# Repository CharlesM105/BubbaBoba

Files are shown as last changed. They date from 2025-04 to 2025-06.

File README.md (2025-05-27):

</head>
<body>

<h1>🧋 Bubba Boba</h1>
<p><strong>An Arduino-powered, fully-automated boba drink dispenser.</strong></p>

<div class="section">
  <h2>✨ Project Overview</h2>
  <p><strong>Bubba Boba</strong> is a fully autonomous boba drink-making robot built using two coordinated Arduino boards: an Arduino Mega and an Arduino Uno. The Mega handles all user interface logic, relay sequencing, and drink recipe control. The Uno exclusively controls mechanical movement: stepper motors, servos, limit switches, and mixers. Together, they synchronize to deliver a customizable, fully-automated boba experience.</p>
  <p>Users can navigate a menu via rotary encoder and LCD display, select a drink, and watch as the machine pours milk, adds flavor, mixes the drink, and finally dispenses boba. A final presentation sequence slides the cup out to the user for pickup. A full-system cleaning mode is also included for maintenance.</p>
</div>

<div class="section">
  <h2>🧠 How It Works (System Architecture)</h2>
  <ul>
    <li><strong>Arduino Mega:</strong> Handles all logic, UI, and relay control.
      <ul>
        <li>Displays menu on LCD and processes rotary encoder input</li>
        <li>Controls timing and sequencing of drink-making steps</li>
        <li>Manages relays for milk and flavor dispensing</li>
        <li>Sends light signal to Uno via onboard LED or relay circuit</li>
      </ul>
    </li>
    <li><strong>Arduino Uno:</strong> Handles mechanical automation.
      <ul>
        <li>Homes all axes on startup using limit switches (X, Y, Z)</li>
        <li>Moves cup into mixing, dispensing, and boba positions</li>
        <li>Operates syrup servo, mixer motor, and boba shaker</li>
        <li>Begins execution when a photoresistor detects the light signal from Mega</li>
      </ul>
    </li>
    <li><strong>Communication:</strong>
      <ul>
        <li>Photoresistor on Uno reads light intensity from a pin-controlled LED on Mega</li>
        <li>Simple analog-based “GO” signal used to trigger the movement sequence</li>
        <li>One-way communication — minimal wiring, no serial protocol needed</li>
      </ul>
    </li>
    <li><strong>Scripts:</strong>
      <ul>
        <li><code>main.ino</code> – runs on Mega (UI, logic, pumps, LED)</li>
        <li><code>movement_sequence.ino</code> – runs on Uno (motors, servo, mixer)</li>
        <li>All other .ino files are test scripts for subsystems (not used in production)</li>
      </ul>
    </li>
  </ul>
</div>

<div class="section">
  <h2>🧰 Features</h2>
  <ul>
    <li>Rotary encoder + 20x4 LCD menu system</li>
    <li>Preset drinks: Classic Tea, Strawberry Milk, Taro Milk Tea</li>
    <li>Servo-controlled syrup dispenser</li>
    <li>Milk and flavor pumps controlled by relays</li>
    <li>Stepper gantry motion on 3 axes</li>
    <li>Boba dispensing via dedicated stepper + shaker motor</li>
    <li>NeoPixel LED animations during each drink phase</li>
    <li>Full-system cleaning mode (30s all-pump activation)</li>
    <li>Diagnostics + manual axis control menus</li>
  </ul>
</div>

<div class="section">
  <h2>💸 Updated Cost Breakdown</h2>
  <p><strong>All items (except milk) were purchased from Amazon.</strong></p>
  <p><strong>The lead screw kit used is generic and is applied throughout the project.</strong></p>
  <p><strong>More detailed parts, source links, and specifications are included in the separate BOM file (Bill of Materials).</strong></p>

  <table>
    <thead>
      <tr><th>Item</th><th>Quantity</th><th>Unit Price</th><th>Total Price</th></tr>
    </thead>
    <tbody>
      <tr><td><strong>Electronics & Hardware</strong></td><td></td><td></td><td></td></tr>
      <tr><td>Arduino Mega 2560</td><td>1</td><td>$49.65</td><td>$49.65</td></tr>
      <tr><td>I2C 20x4 LCD Display</td><td>1</td><td>$13.76</td><td>$13.76</td></tr>
      <tr><td>Rotary Encoder</td><td>1</td><td>$8.89</td><td>$8.89</td></tr>
      <tr><td>V-Slot Screws (25 pcs)</td><td>1</td><td>$2.36</td><td>$2.36</td></tr>
      <tr><td>Buttons (for axis limits)</td><td>3</td><td>$1.00</td><td>$3.00</td></tr>
      <tr><td>Lead Screw Kit</td><td>1</td><td>$18.45</td><td>$18.45</td></tr>
      <tr><td>Stepper Motor (Single)</td><td>1</td><td>$14.32</td><td>$14.32</td></tr>
      <tr><td>Motor Drivers (4-pack)</td><td>1</td><td>$9.99</td><td>$9.99</td></tr>
      <tr><td>12V DC Motor</td><td>1</td><td>$14.99</td><td>$14.99</td></tr>
      <tr><td>Mini 5V Motors (3-pack)</td><td>1</td><td>$7.99</td><td>$7.99</td></tr>
      <tr><td>Buck Converters (3-pack)</td><td>1</td><td>$14.99</td><td>$14.99</td></tr>
      <tr><td>120mm Fans</td><td>2</td><td>$6.00</td><td>$12.00</td></tr>
      <tr><td>Acrylic Sheets</td><td>2</td><td>$10.00</td><td>$20.00</td></tr>
      <tr><td>Cups (100-pack)</td><td>1</td><td>$16.99</td><td>$16.99</td></tr>
      <tr><td>Boba Flavor Kits</td><td>3</td><td>$22.00</td><td>$66.00</td></tr>
      <tr><td>Milk</td><td>2</td><td>$4.50</td><td>$9.00</td></tr>
      <tr><td>Thin Wood Sheets (6-pack)</td><td>1</td><td>$10.00</td><td>$10.00</td></tr>
      <tr><td>Diaphragm Pumps</td><td>4</td><td>$8.00</td><td>$32.00</td></tr>
      <tr><td>LED Strips (optional)</td><td>2</td><td>$10.00</td><td>$20.00</td></tr>
      <tr><td>Relay Modules (10-pack)</td><td>1</td><td>$12.00</td><td>$12.00</td></tr>
      <tr><td>Tubing</td><td>1</td><td>$5.00</td><td>$5.00</td></tr>
      <tr><td><strong>Recycled Ender 3 V1 Parts (Rails, Mounts, Power Supply)</strong></td><td>–</td><td>$0.00</td><td>$0.00</td></tr>
      <tr><td>Black PLA (2 partial rolls)</td><td>1</td><td>$15.00</td><td>$15.00</td></tr>
      <tr><td>Gold PLA (partial roll)</td><td>1</td><td>$7.50</td><td>$7.50</td></tr>
      <tr><td>Gray PLA (partial roll)</td><td>1</td><td>$7.50</td><td>$7.50</td></tr>
      <tr><td>Clear PLA (partial roll)</td><td>1</td><td>$7.50</td><td>$7.50</td></tr>
      <tr><td>White PLA (partial roll)</td><td>1</td><td>$7.50</td><td>$7.50</td></tr>
      <tr><th colspan="3">Total Estimated Cost</th><th>$450.83</th></tr>
    </tbody>
  </table>

  <h3>📝 Notes</h3>
  <ul>
    <li>Prices are based on average market values as of May 2025 and may vary depending on supplier and shipping.</li>
    <li><strong>Tariff and import duty costs are not reflected in these estimates.</strong></li>
    <li>Partial PLA rolls are estimated at 50% of a full roll (approx. 500g).</li>
    <li>Optional components (e.g., LED strips) can be excluded to lower costs.</li>
    <li>Most <strong>design elements</strong> were 3D printed; their cost is factored into filament pricing.</li>
  </ul>
</div>

<div class="section">
  <h2>📊 Project Timeline (Gantt Chart)</h2>
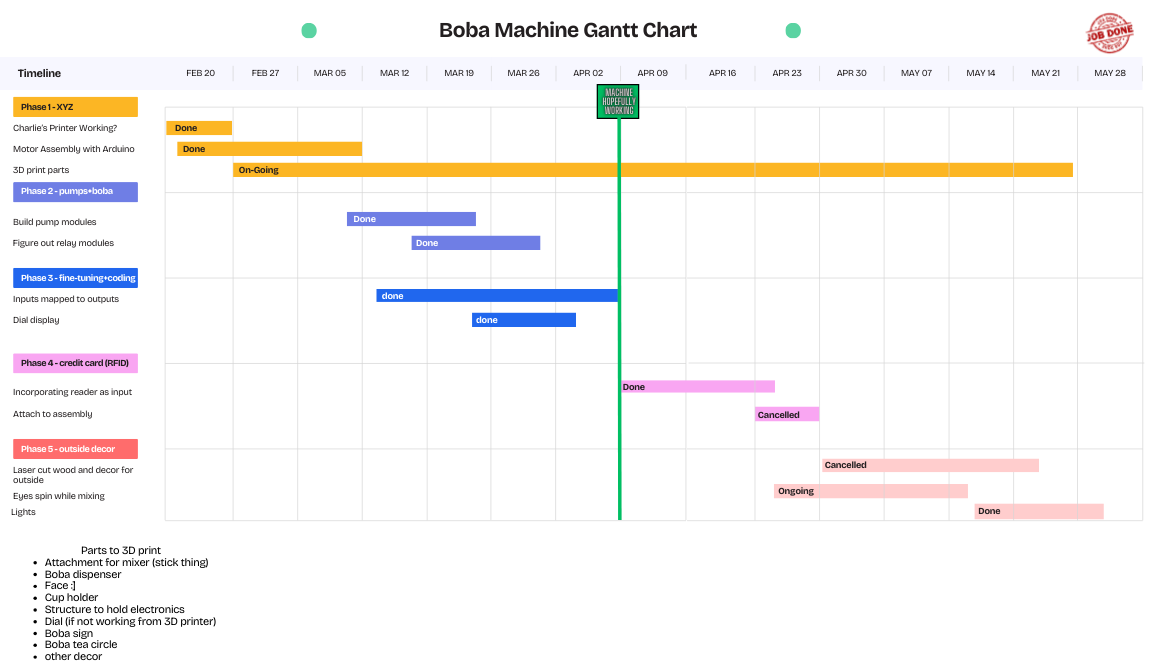
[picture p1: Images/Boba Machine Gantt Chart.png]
Bubba Boba Gantt Chart
  
</div>

<div class="section">
  <h2>📸 Demo Gallery</h2>
  <div>
    <h4>Final Build</h4>
    Final Build
    <h4>LCD UI</h4>
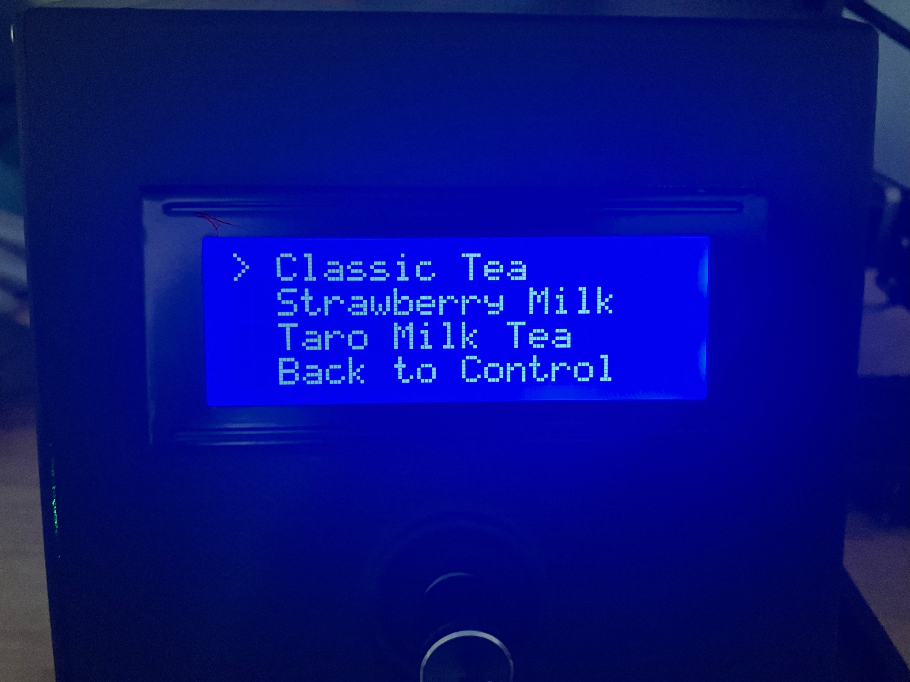
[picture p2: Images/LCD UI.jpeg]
LCD UI
    
    <h4>Ground Zero (Workstation Chaos)</h4>
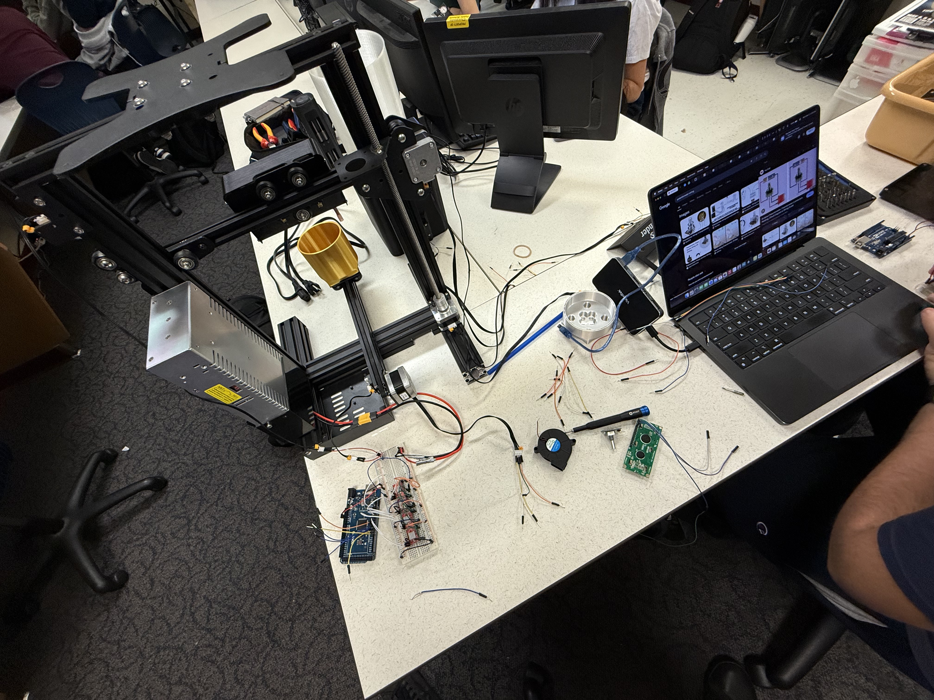
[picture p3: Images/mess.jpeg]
Ground Zero
    
    <h4>LED Strip Animation</h4>
    LED Strip Animation
    <h4>Stepper Motor Homing Sequence</h4>
    Stepper Motor Gantry
    <h4>Main Board Wiring</h4>
    Main Board
    <h4>Stepper Motors on Mega</h4>
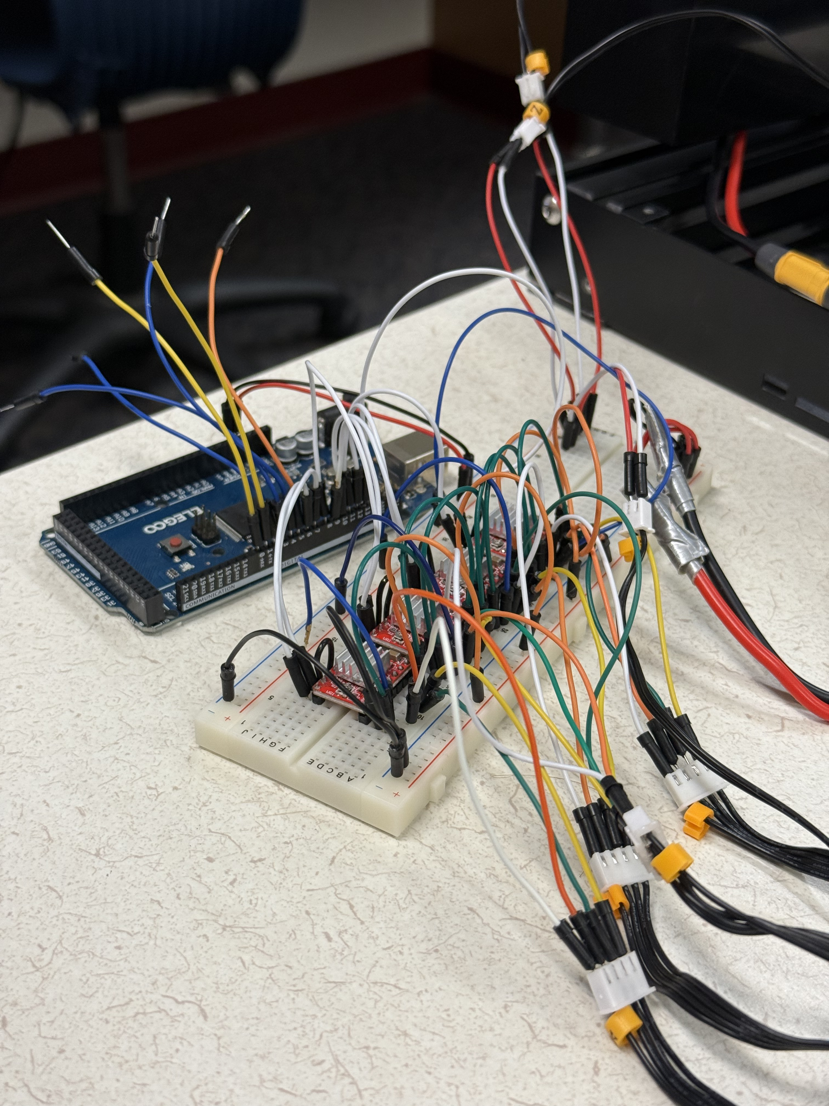
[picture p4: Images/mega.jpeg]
Stepper Motors
    
    <h4>Wire Management</h4>
    Wires
  </div>
</div>

<div class="section">
  <h2>🔌 Wiring Overview</h2>
  <p>All wiring documentation is included in <code>/docs</code>. Major components include:</p>
  <ul>
    <li>10V power for motors and pumps</li>
    <li>6V regulated for logic boards</li>
    <li>Limit switches on all axes</li>
    <li>Relay-controlled liquid pumps</li>
    <li>LED → photoresistor communication line between Mega and Uno</li>
  </ul>
</div>
</div>
      <h2>🔌 Wiring Diagram</h2>
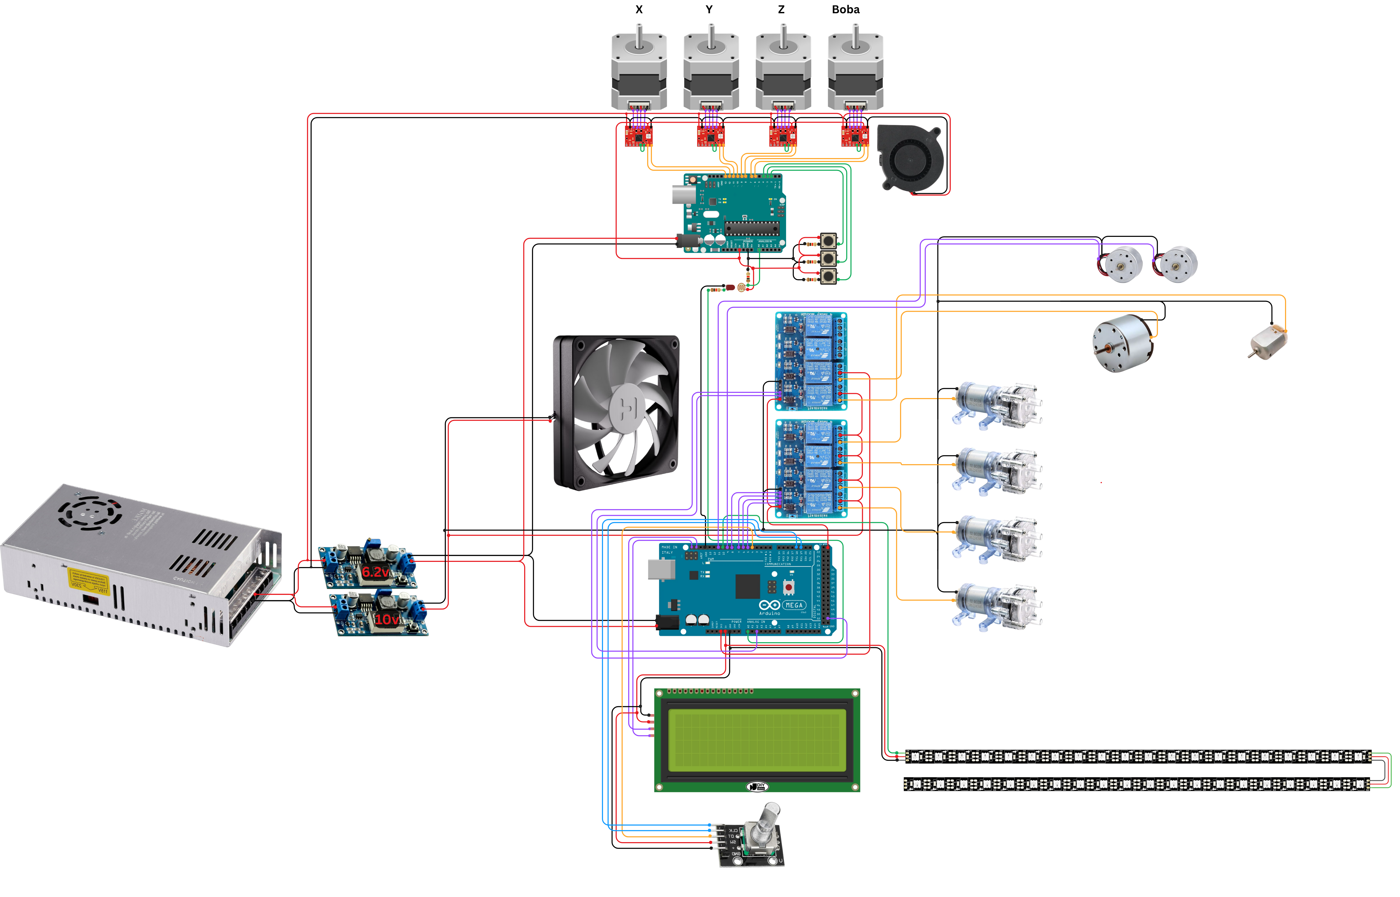
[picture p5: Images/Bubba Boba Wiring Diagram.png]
Bubba Boba Gantt Chart
  

<div class="section">
  <h2>📜 License</h2>
  <p>This project is licensed under the <a href="https://opensource.org/licenses/MIT" target="_blank">MIT License</a>.</p>
</div>

<div class="section">
  <h2>🙌 Credits</h2>
  <p>Created by <strong>Charles Mastromatteo, Sabrina Maule, and Vincent Larson</strong></p>
  <p>Special thanks to: Arduino forums, Adafruit libraries, and the online maker community.</p>
</div>

</body>
</html>

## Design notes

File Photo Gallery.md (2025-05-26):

<!DOCTYPE html>
<html lang="en">
<head>
  <meta charset="UTF-8">

</head>
<body>

  <h1>📸 Bubba Boba Photo Gallery</h1>

  <div class="gallery">
    <div class="photo-box">
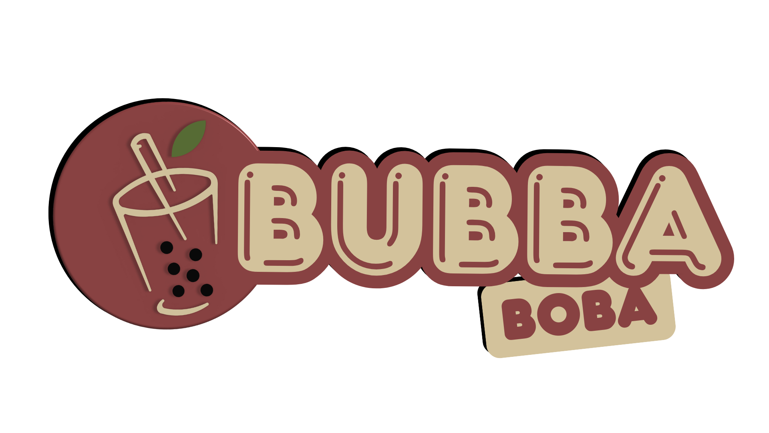
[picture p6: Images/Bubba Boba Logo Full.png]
Insert Image 1
      
    </div>
    <div class="photo-box">
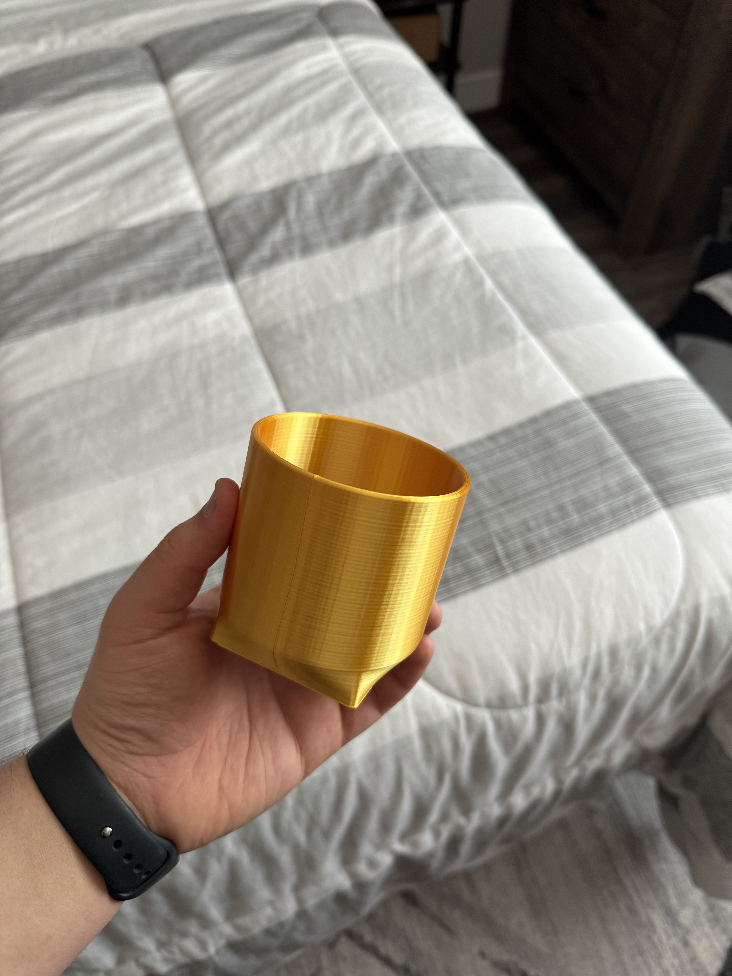
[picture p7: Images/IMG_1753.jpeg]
Insert Image 2
      
    </div>
    <div class="photo-box">
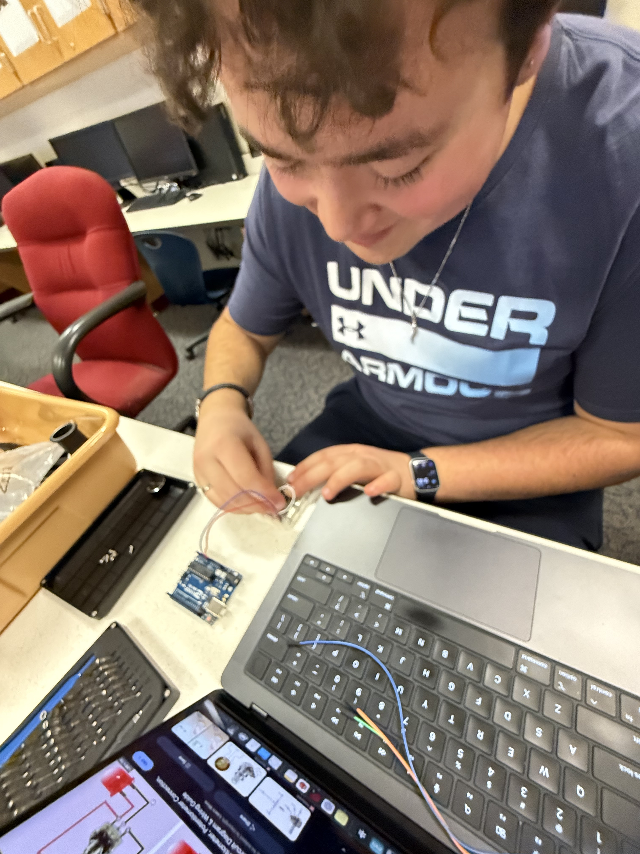
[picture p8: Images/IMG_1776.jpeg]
Insert Image 3
      
    </div>
    <div class="photo-box">
      Insert Image 4
    </div>
    <div class="photo-box">
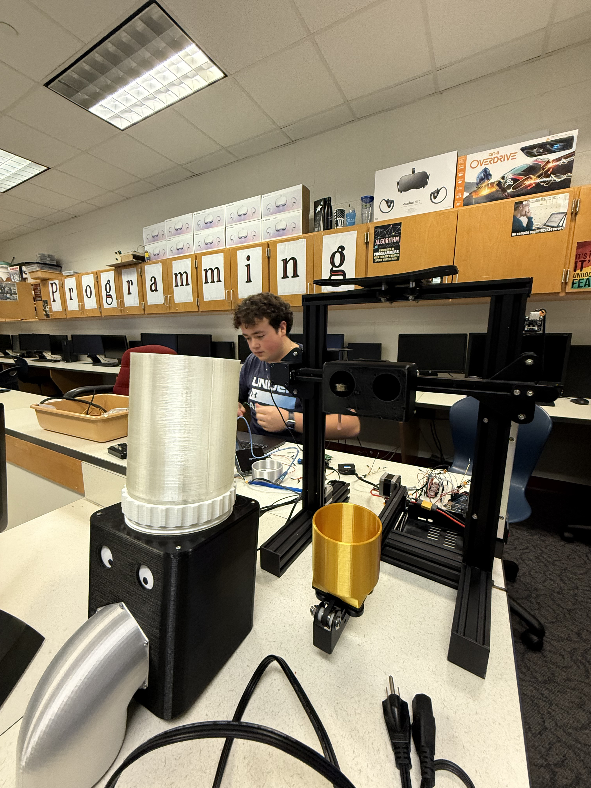
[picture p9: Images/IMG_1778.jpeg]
Insert Image 5
      
    </div>
    <div class="photo-box">
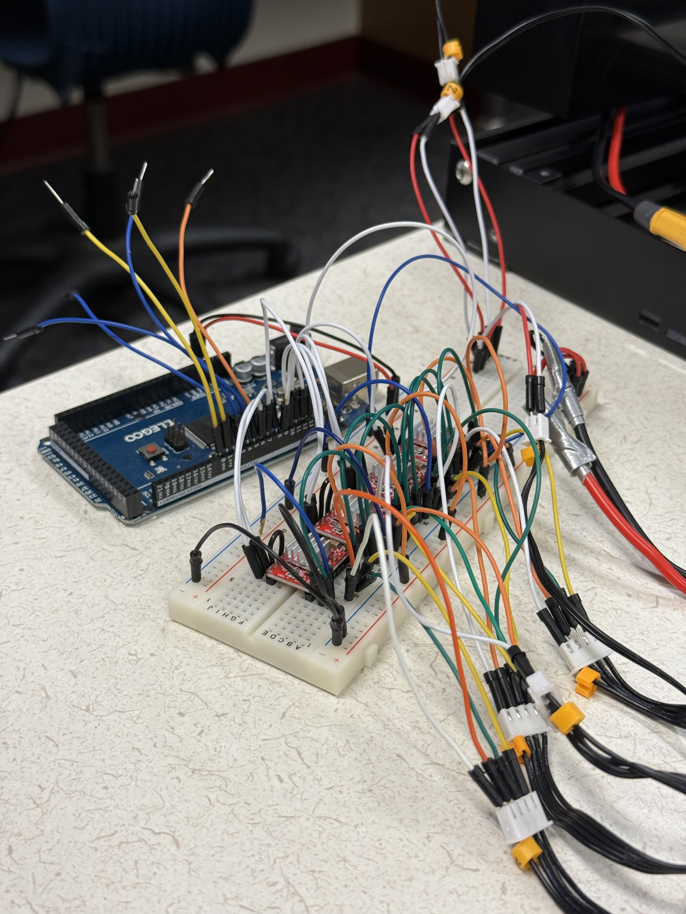
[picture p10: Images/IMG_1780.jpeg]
Insert Image 6
      
    </div>
        <div class="photo-box">
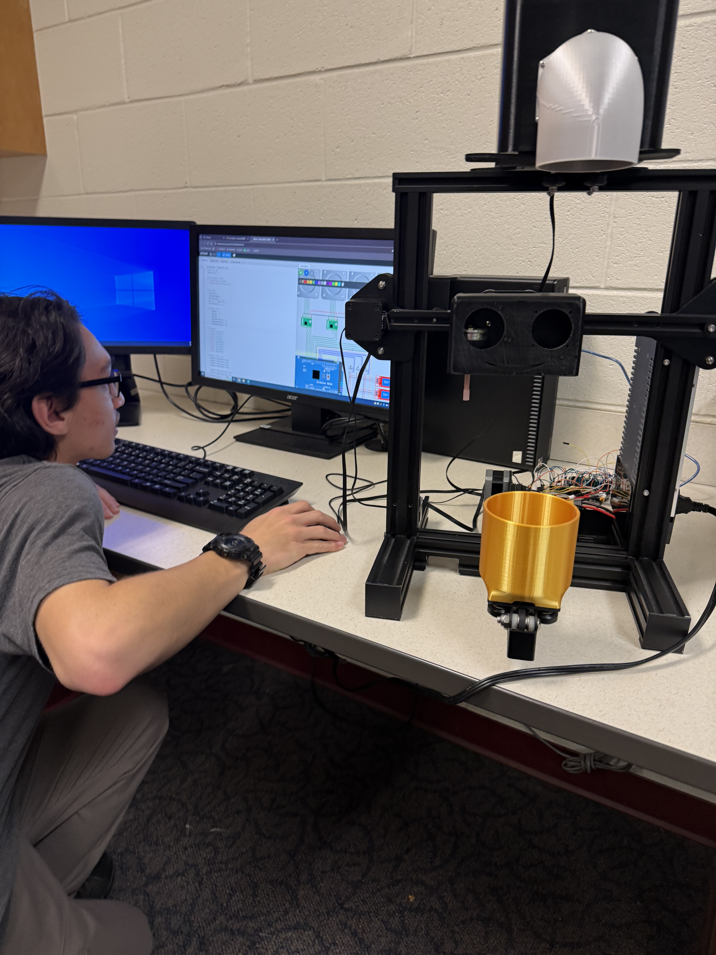
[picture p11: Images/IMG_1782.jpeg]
Insert Image 6
      
    </div>
        <div class="photo-box">
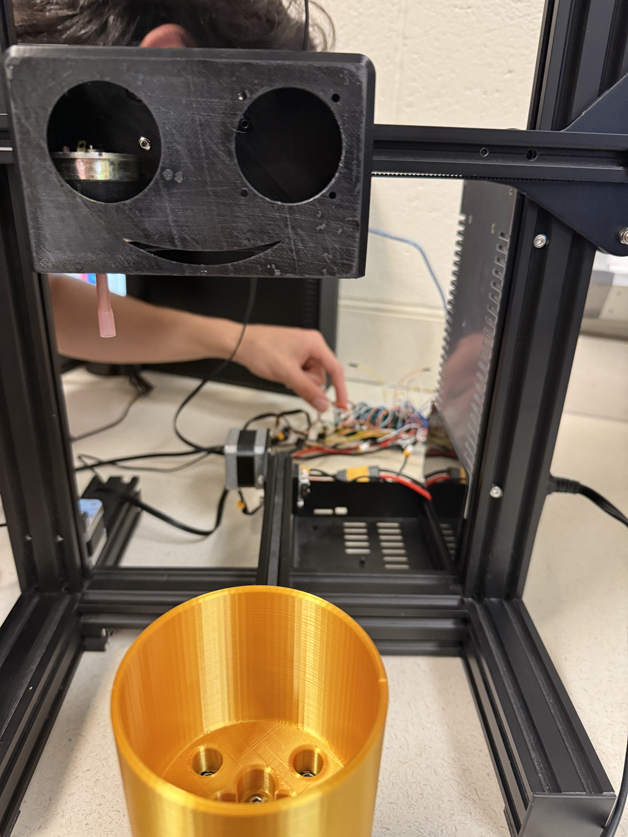
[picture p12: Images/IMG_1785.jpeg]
Insert Image 6
      
    </div>
        <div class="photo-box">
      Insert Image 6
              </div>
            <div class="photo-box">
      Insert Image 6
              </div>
                <div class="photo-box">
      Insert Image 6
              </div>
                    <div class="photo-box">
      Insert Image 6
              </div>
                    <div class="photo-box">
      Insert Image 6
              </div>
                    <div class="photo-box">
      Insert Image 6
              </div>
                    <div class="photo-box">
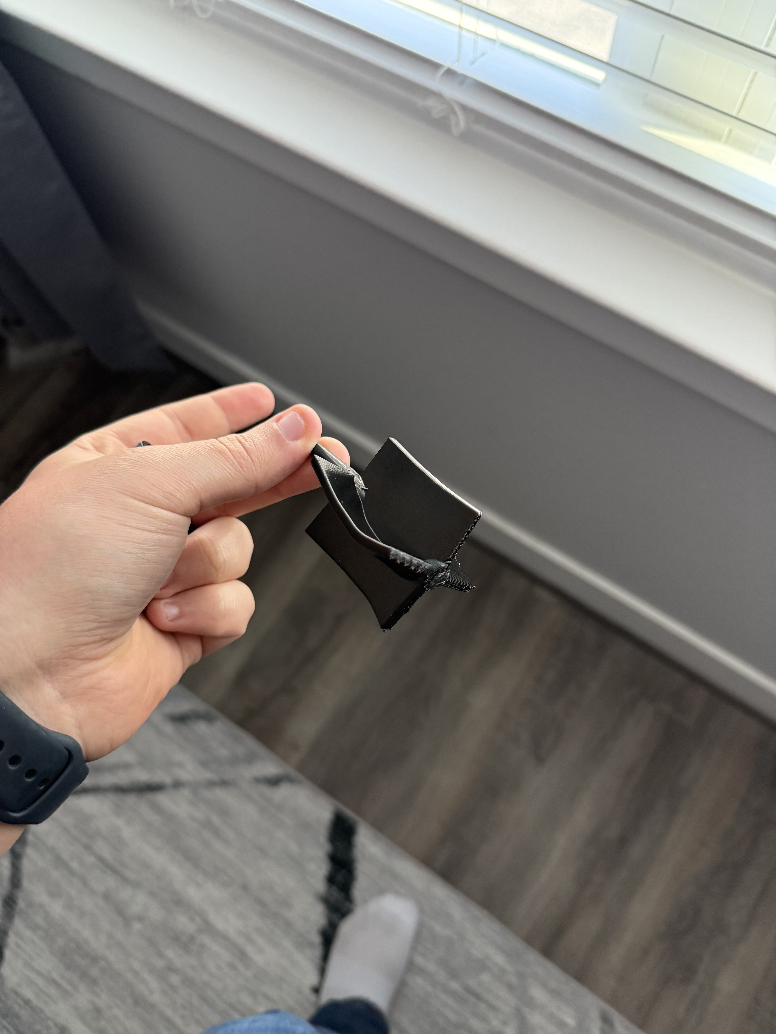
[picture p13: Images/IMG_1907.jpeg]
Insert Image 6
      
              </div>
                    <div class="photo-box">
      Insert Image 6
              </div>
                        <div class="photo-box">
      Insert Image 6
              </div>
                        <div class="photo-box">
      Insert Image 6
              </div>
                        <div class="photo-box">
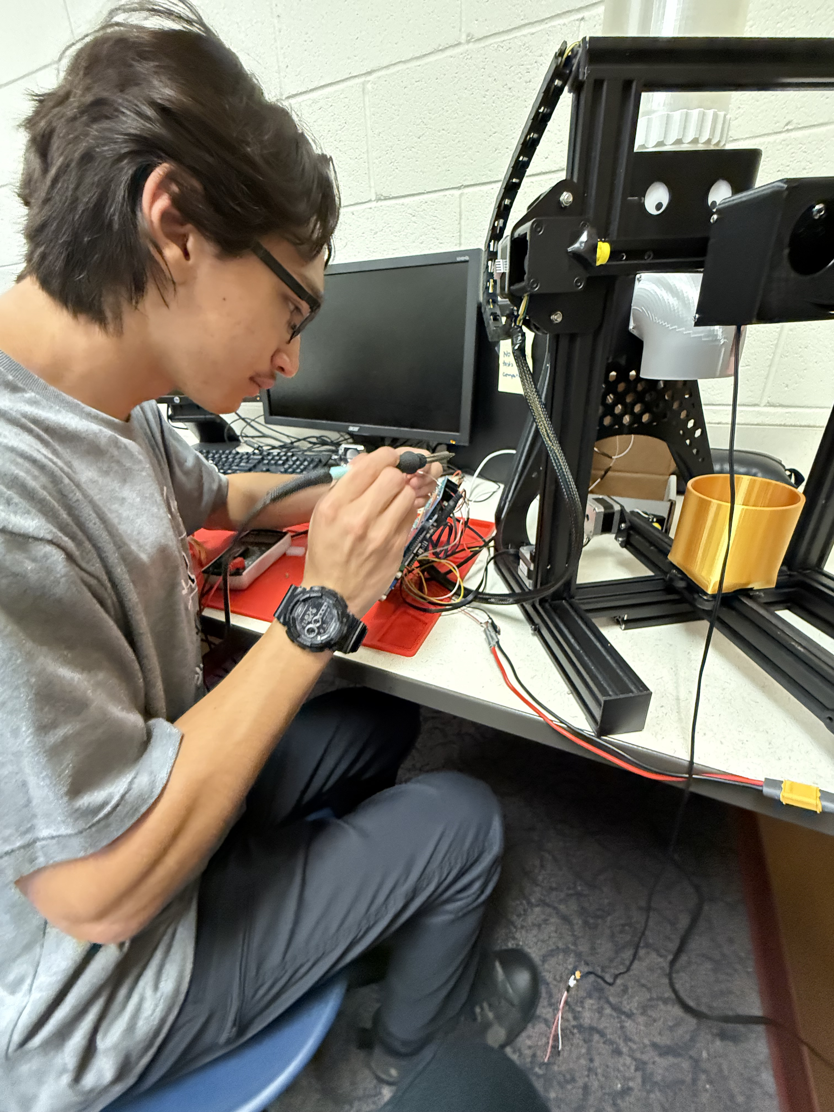
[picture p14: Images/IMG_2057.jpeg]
Insert Image 6
      
                                                  <div class="photo-box">
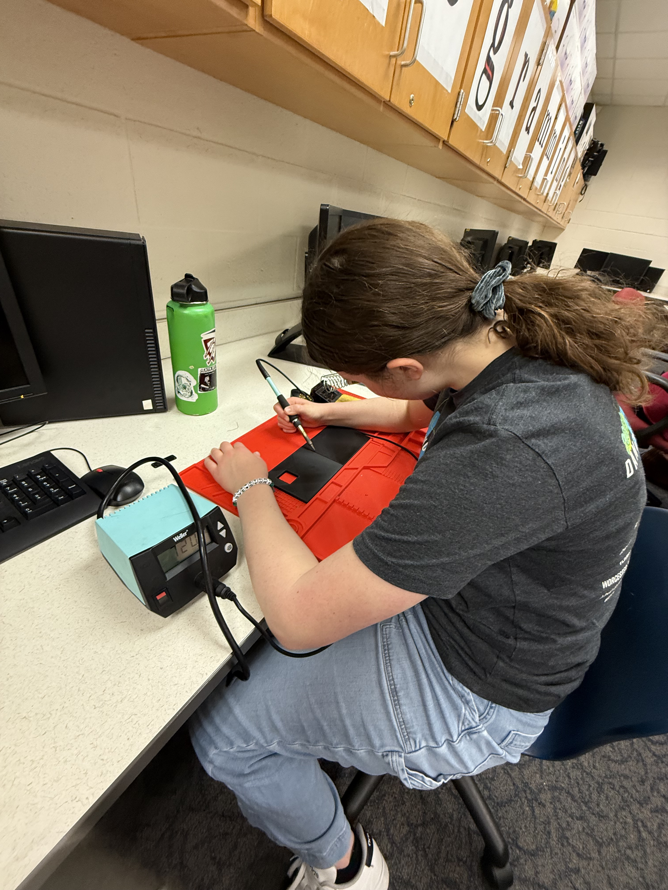
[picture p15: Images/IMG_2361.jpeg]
Insert Image 6
      
              </div>
                        <div class="photo-box">
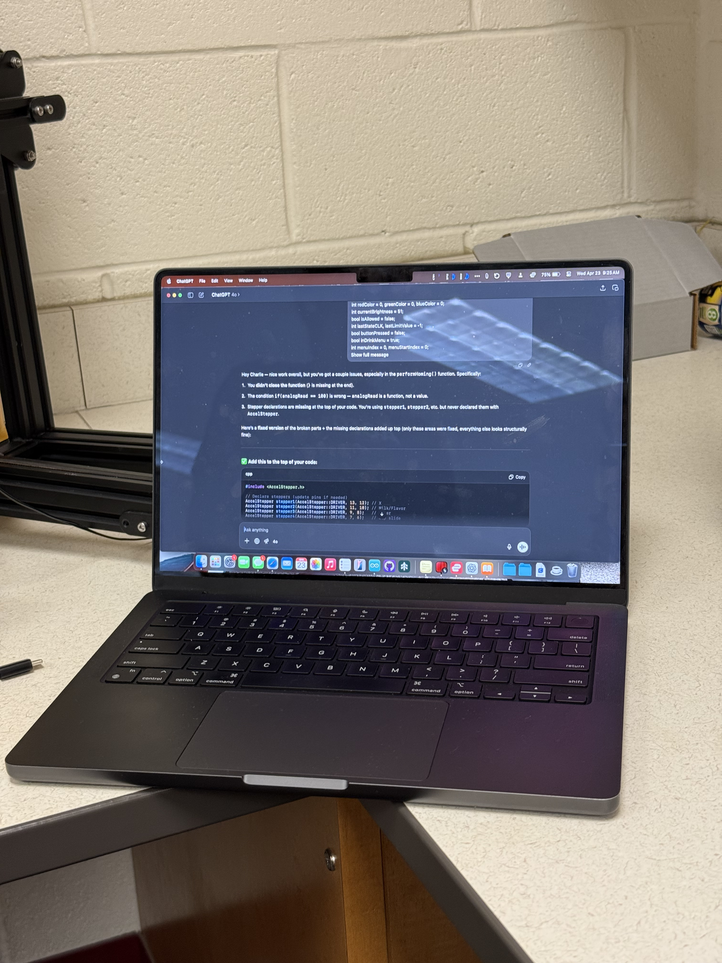
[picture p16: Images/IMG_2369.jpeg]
Insert Image 6
      
              </div>
                        <div class="photo-box">
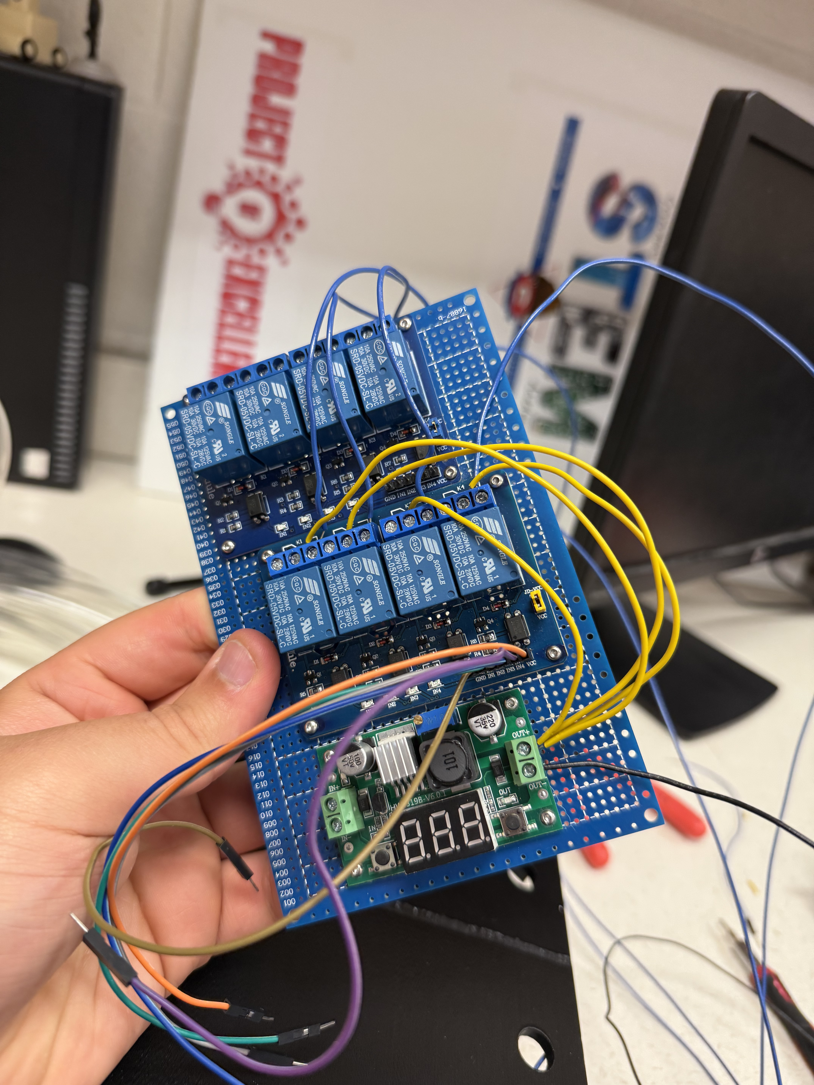
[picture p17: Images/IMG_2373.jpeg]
Insert Image 6
      
              </div>
                                                  <div class="photo-box">
      Insert Image 6
              </div>
                        <div class="photo-box">
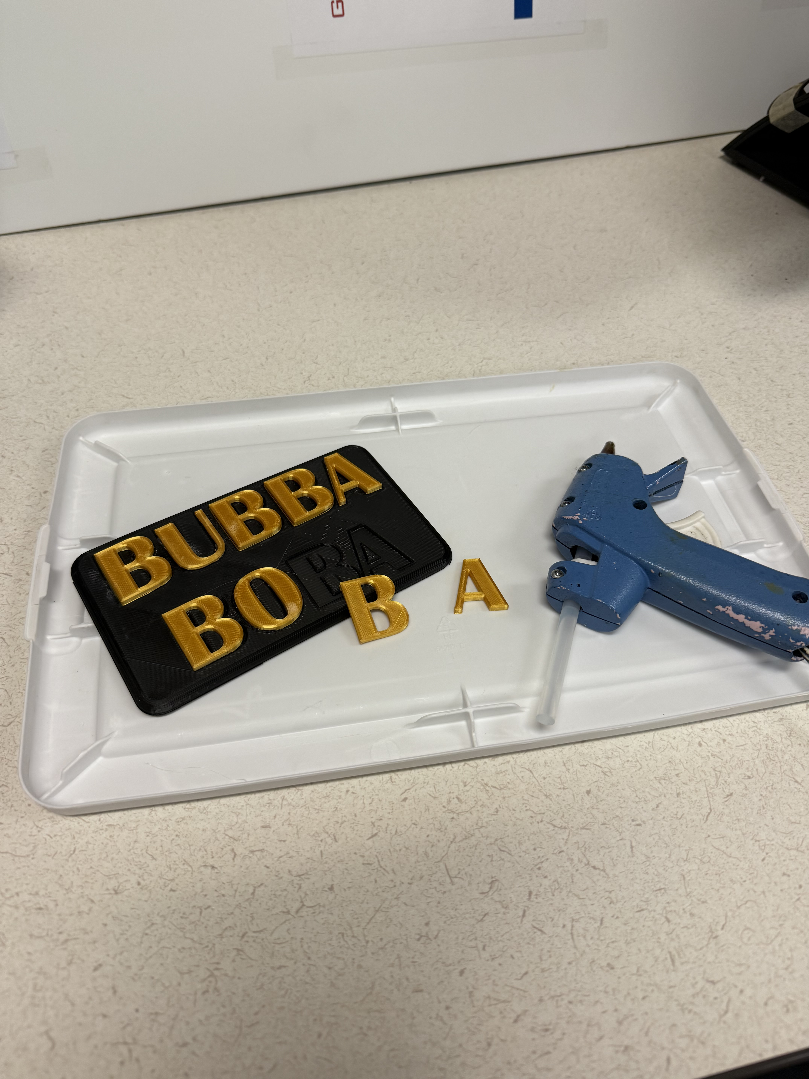
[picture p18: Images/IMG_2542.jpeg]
Insert Image 6
      
              </div>
                        <div class="photo-box">
      Insert Image 6
    </div>
                            <div class="photo-box">
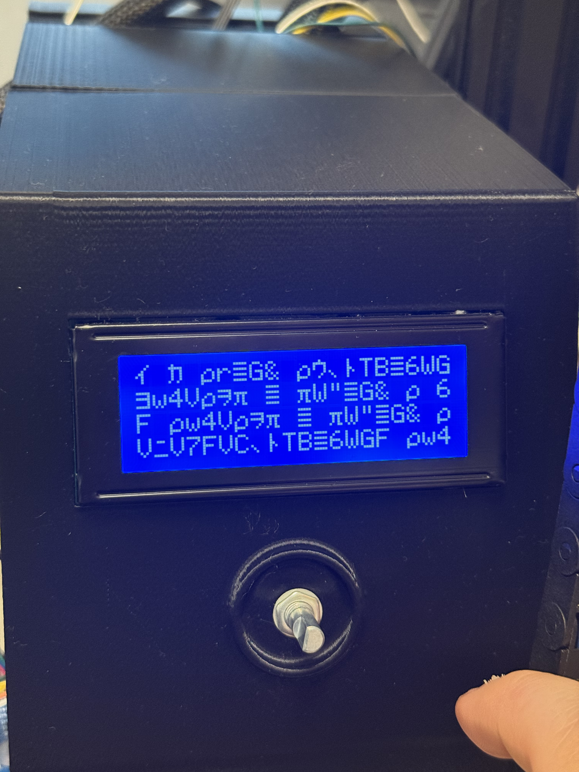
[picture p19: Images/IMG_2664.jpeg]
Insert Image 6
      
              </div>
                        <div class="photo-box">
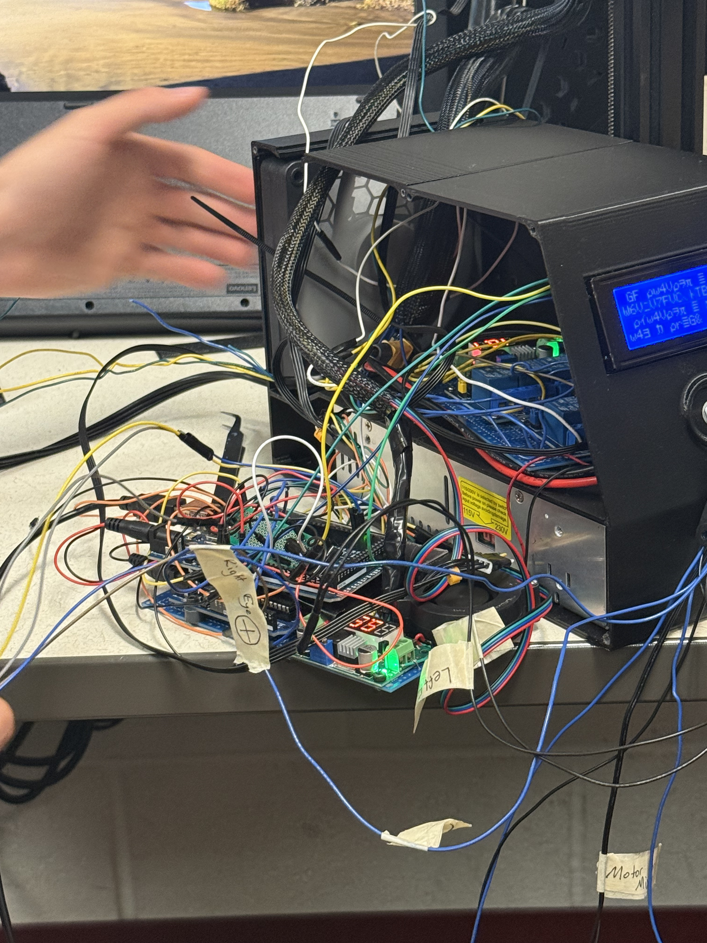
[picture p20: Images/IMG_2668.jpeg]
Insert Image 6
      
                                                  <div class="photo-box">
      Insert Image 6
              </div>
                                                  <div class="photo-box">
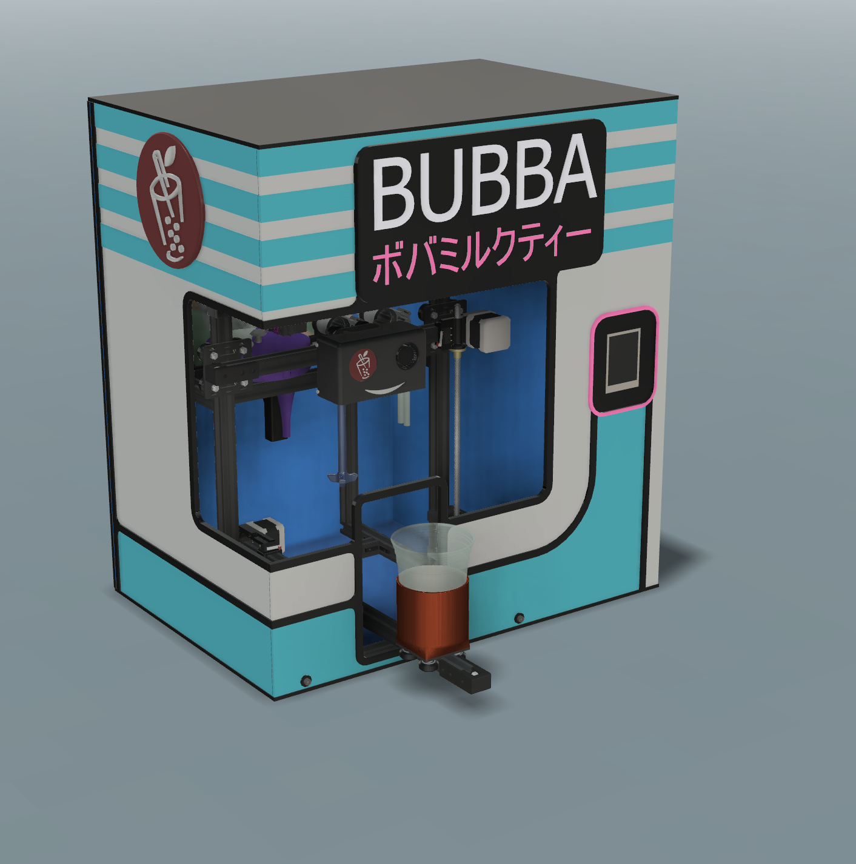
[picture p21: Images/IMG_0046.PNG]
Insert Image 6
      
              </div>
                        <div class="photo-box">
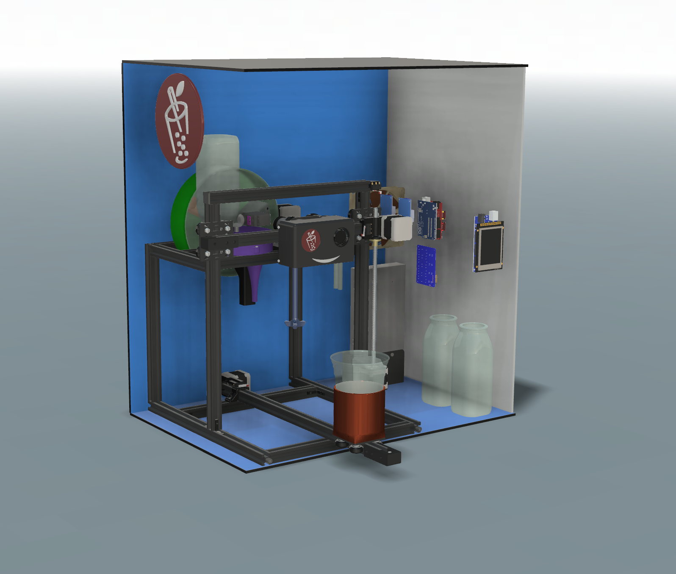
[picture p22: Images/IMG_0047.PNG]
Insert Image 6
      
    </div>
                            <div class="photo-box">
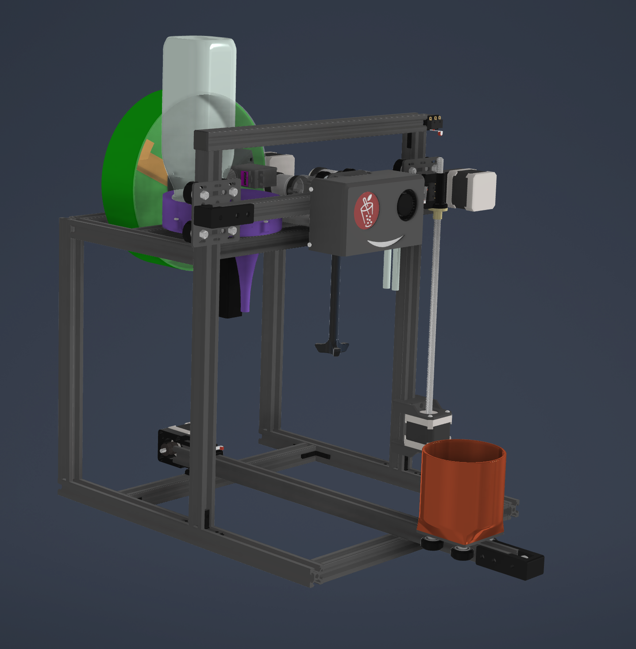
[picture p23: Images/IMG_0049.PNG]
Insert Image 6
      
              </div>
                        <div class="photo-box">
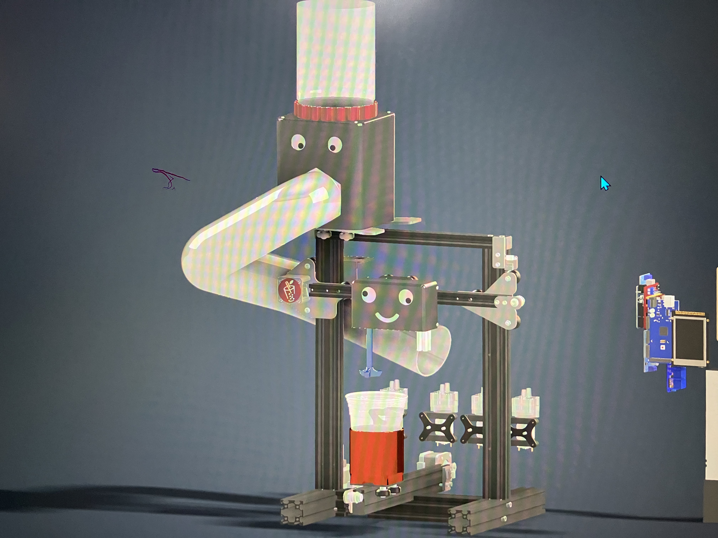
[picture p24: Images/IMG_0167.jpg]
Insert Image 6
      
              </div>
                                                  <div class="photo-box">
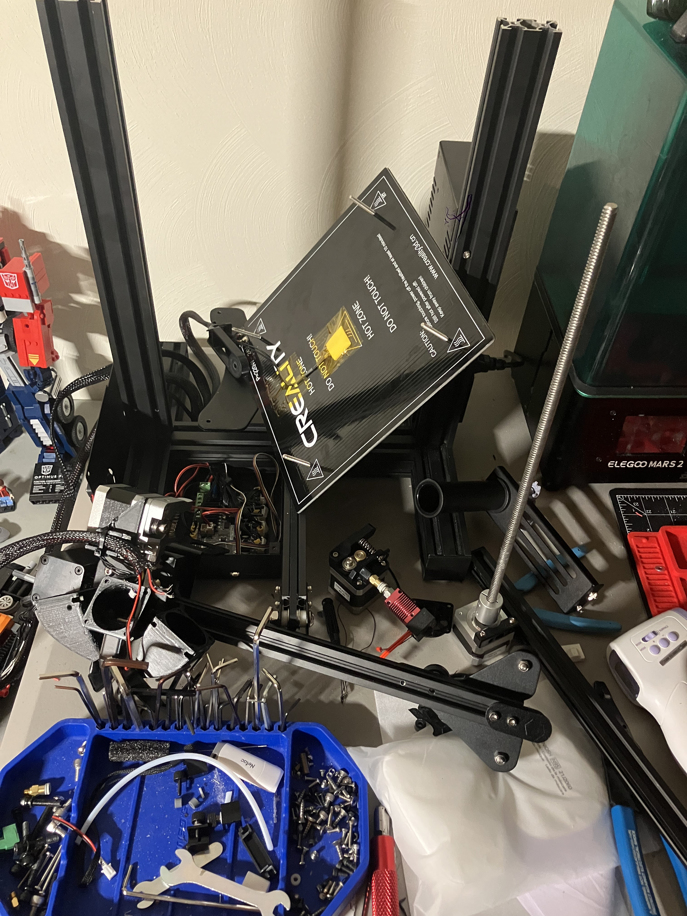
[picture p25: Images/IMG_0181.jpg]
Insert Image 6
      
              </div>
                                                  <div class="photo-box">
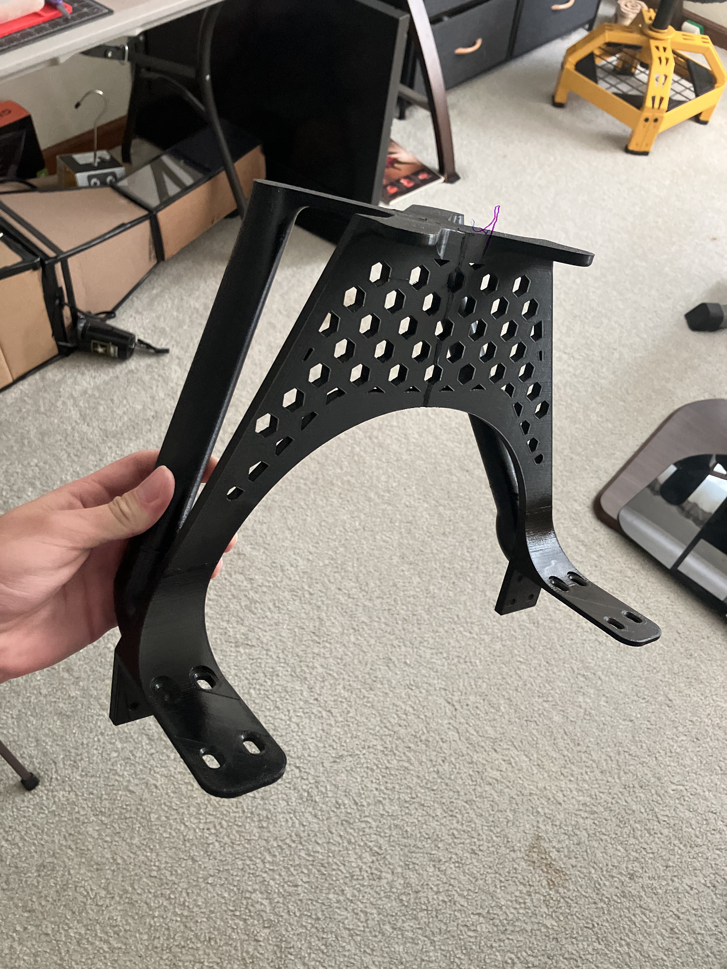
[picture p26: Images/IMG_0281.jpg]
Insert Image 6
      
              </div>
                                                  <div class="photo-box">
      Insert Image 6
              </div>
                                                  <div class="photo-box">
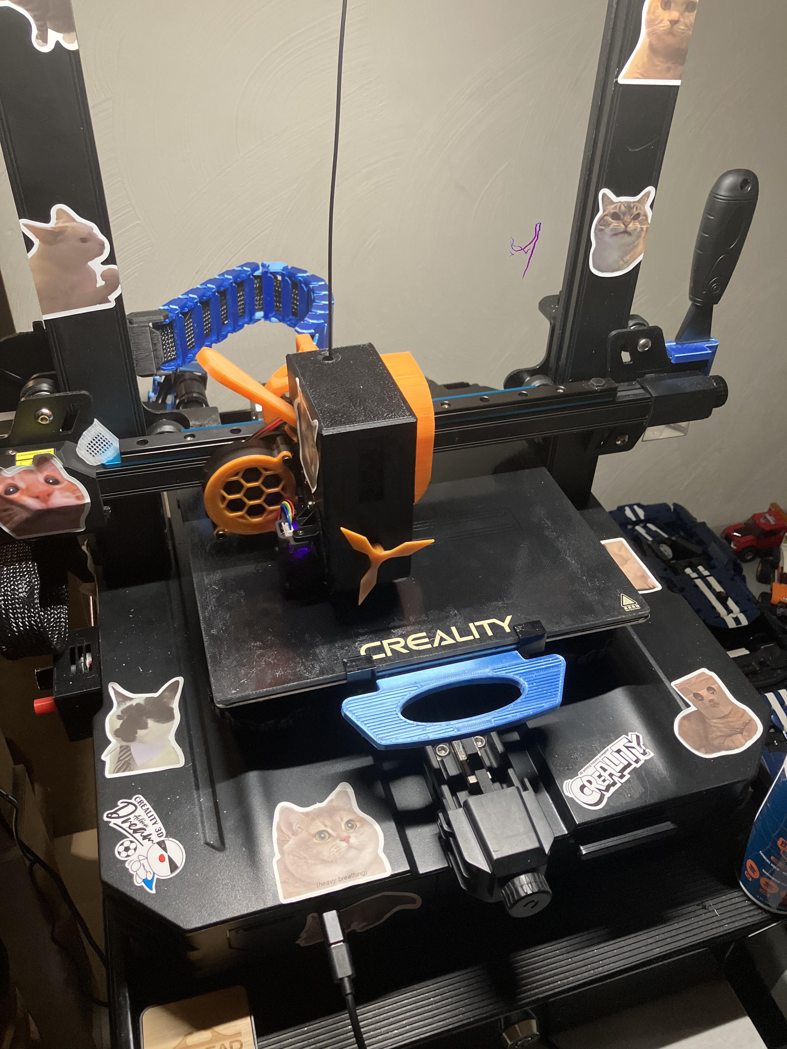
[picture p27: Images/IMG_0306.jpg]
Insert Image 6
      
              </div>
                                                  <div class="photo-box">
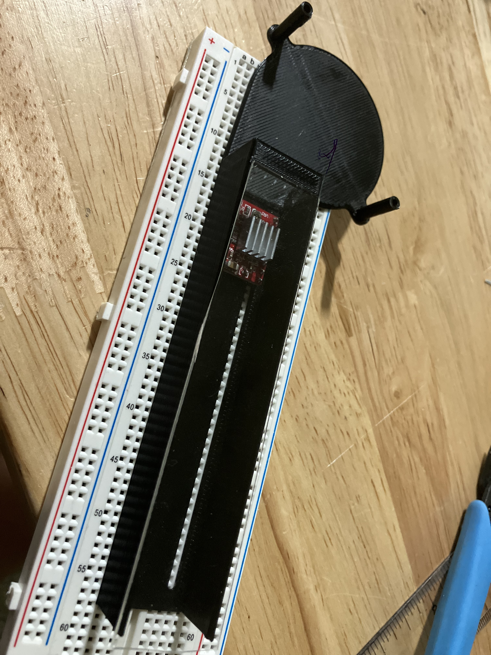
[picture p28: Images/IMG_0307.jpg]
Insert Image 6
      
              </div>
                                                  <div class="photo-box">
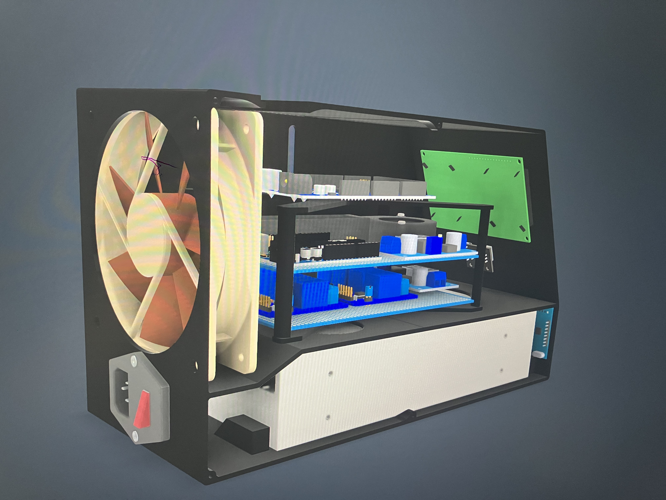
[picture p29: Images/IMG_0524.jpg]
Insert Image 6
      
              </div>
                          <div class="photo-box">
      Insert Image 6
              </div>
                        <div class="photo-box">
      Insert Image 6
              </div>
                        <div class="photo-box">
      Insert Image 6
              </div>
                                                  <div class="photo-box">
      Insert Image 6
    </div>
                            <div class="photo-box">
      Insert Image 6
              </div>
                        <div class="photo-box">
      Insert Image 6
                                                  <div class="photo-box">
      Insert Image 6
              </div>
                        
      Insert Image 6
              </div>
  </div>

</body>
</html>

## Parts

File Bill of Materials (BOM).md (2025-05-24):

</head>
<body>

<h1>🧋 Bubba Boba – Bill of Materials (BOM)</h1>

<div class="note">
  <strong>Note:</strong> All items listed below were purchased from Amazon, <u>except milk</u> which was bought locally. The Lead Screw Kit listed is a generic kit used in multiple areas throughout the project.
</div>

<h2>✅ With 3D Printer (Reused Ender 3 Parts)</h2>
<table>
  <thead>
    <tr><th>Item</th><th>Cost</th><th>Purchase Link</th></tr>
  </thead>
  <tbody>
    <tr><td>Arduino Mega 2560</td><td>$49.65</td><td><a href="https://www.amazon.com/ARDUINO-MEGA-2560-REV3-A000067/dp/B0046AMGW0">Buy</a></td></tr>
    <tr><td>I2C 20x4 LCD Display</td><td>$13.76</td><td><a href="https://www.amazon.com/dp/B082Y37WXG">Buy</a></td></tr>
    <tr><td>Rotary Encoder</td><td>$8.89</td><td><a href="https://www.amazon.com/HiLetgo-Degrees-Rotary-Encoder-Arduino/dp/B07WZF1TXX">Buy</a></td></tr>
    <tr><td>V-Slot Screws (25 pcs)</td><td>$2.36</td><td><a href="https://www.amazon.com/dp/B0BZP8T639">Buy</a></td></tr>
    <tr><td>Buttons (Limit Switches)</td><td>$3.00</td><td><a href="https://www.amazon.com/dp/B07X142VGC">Buy</a></td></tr>
    <tr><td>Lead Screw Kit (Generic)</td><td>$18.45</td><td>Reused</td></tr>
    <tr><td>Stepper Motor</td><td>$14.32</td><td><a href="https://www.amazon.com/dp/B0CX91RHF9">Buy</a></td></tr>
    <tr><td>Motor Drivers (4-pack)</td><td>$9.99</td><td><a href="https://www.amazon.com/WWZMDiB-Stepstick-Stepper-Printer-Suitable/dp/B0BFQZWT6R">Buy</a></td></tr>
    <tr><td>12V DC Motor</td><td>$14.99</td><td><a href="https://www.amazon.com/Greartisan-Electric-Reduction-Eccentric-Diameter/dp/B072KNG6NT">Buy</a></td></tr>
    <tr><td>Mini 5V Motors (3-pack)</td><td>$7.99</td><td><a href="https://www.amazon.com/dp/B0D6DR31TS">Buy</a></td></tr>
    <tr><td>Buck Converters (3-pack)</td><td>$14.99</td><td><a href="https://www.amazon.com/dp/B0BTBVDB4S">Buy</a></td></tr>
    <tr><td>120mm Fans (2x)</td><td>$12.00</td><td><a href="https://www.amazon.com/Antec-120mm-Performance-Connector-Computer/dp/B09X1FS4YM">Buy</a></td></tr>
    <tr><td>Acrylic Sheets (2x)</td><td>$20.00</td><td><a href="https://www.amazon.com/KINLINK-Plexiglass-Transparent-Protective-invitaton/dp/B0D1K23JLC">Buy</a></td></tr>
    <tr><td>Cups (100-pack)</td><td>$16.99</td><td><a href="https://www.amazon.com/dp/B0CN6QLR7Q">Buy</a></td></tr>
    <tr><td>Boba Flavor Kits</td><td>$66.00</td><td><a href="https://www.amazon.com/dp/B0DGV6JHVJ">Buy</a></td></tr>
    <tr><td>Milk</td><td>$9.00</td><td>Walmart</td></tr>
    <tr><td>Thin Wood Sheets (6-pack)</td><td>$10.00</td><td><a href="https://www.amazon.com/dp/B0D5VBDC6M">Buy</a></td></tr>
    <tr><td>Diaphragm Pumps (4x)</td><td>$32.00</td><td><a href="https://www.amazon.com/dp/B09ZX4TFNG">Buy</a></td></tr>
    <tr><td>LED Strips (optional)</td><td>$20.00</td><td><a href="https://www.amazon.com/BTF-LIGHTING-WS2812B5M60LB30-BTF-LIGHTING-WS2812B-IC-RGB-5050SMD-Pure-Gold-Individual-Addressable-LED-Strip-High-Quality-16-4FT-300LED-60LED-m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">Buy</a></td></tr>
    <tr><td>Relay Modules (10-pack)</td><td>$12.00</td><td><a href="https://www.amazon.com/dp/B0972R8QZS">Buy</a></td></tr>
    <tr><td>Tubing</td><td>$5.00</td><td><a href="https://www.amazon.com/dp/B0852JYLVG">Buy</a></td></tr>
    <tr><td>PLA Filament (partial rolls)</td><td>$45.00</td><td><a href="https://www.amazon.com/dp/B00J0ECR5I">Buy</a></td></tr>
    <tr class="total"><td>Total (With 3D Printer)</td><td colspan="2">$406.38</td></tr>
  </tbody>
</table>

<h2>🚫 Additional Parts (Without 3D Printer)</h2>
<table>
  <thead>
    <tr><th>Item</th><th>Cost</th><th>Purchase Link</th></tr>
  </thead>
  <tbody>
    <tr><td>Aluminum V-Slot Rails + Connectors</td><td>$65.00</td><td><a href="https://www.amazon.com/dp/B07BQYX1JC">Buy</a></td></tr>
    <tr><td>Stepper Motors (x3)</td><td>$42.96</td><td><a href="https://www.amazon.com/dp/B0CX91RHF9">Buy</a></td></tr>
    <tr><td>Timing Belts + Pulleys</td><td>$17.25</td><td><a href="https://www.amazon.com/dp/B07JKT5BZQ">Buy</a></td></tr>
    <tr><td>3-Wheel Gantry Plate</td><td>$6.75</td><td><a href="https://www.amazon.com/dp/B09VC1PWLL">Buy</a></td></tr>
    <tr><td>4-Wheel Gantry Plates (x3)</td><td>$44.67</td><td><a href="https://www.amazon.com/dp/B0986PYTNJ">Buy</a></td></tr>
    <tr><td>12V Power Supply</td><td>$8.99</td><td><a href="https://www.amazon.com/dp/B01N2JGWQ3">Buy</a></td></tr>
    <tr class="total"><td>Total Add-On (No 3D Printer)</td><td colspan="2">$185.62</td></tr>
    <tr class="total"><td>💰 Final Total (No 3D Printer)</td><td colspan="2">$592.00</td></tr>
  </tbody>
</table>

<h3>📜 License</h3>
<p>This project is licensed under the <a href="https://opensource.org/licenses/MIT" target="_blank">MIT License</a>.</p>

<h3>🙌 Credits</h3>
<p>Created by <strong>Charles Mastromatteo, Sabrina Maule, and Vincent Lawrson</strong></p>
<p>Special thanks to the Arduino forums, Adafruit libraries, and the online maker community.</p>

</body>
</html>

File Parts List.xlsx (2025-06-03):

Part | Quantity | Cost | Link
PARTS:
Ender 3 | 1 | $179 | https://www.amazon.com/Comgrow-Creality-Ender-Aluminum-220x220x250mm/dp/B07BR3F9N6
Arduino Uno R3 | 1 | $27.60 | https://www.amazon.com/Arduino-A000066-ARDUINO-UNO-R3/dp/B008GRTSV6?s=electronics
Arduino Mega 2560 | 1 | $49.65 | https://www.amazon.com/ARDUINO-MEGA-2560-REV3-A000067/dp/B0046AMGW0?s=electronics
4x6" Protoboard | 2 (3 pack) | $9.99 | https://www.amazon.com/YUNGUI-Protoboard-Solderable-Breadboard-Electronics/dp/B0921Q1C68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
20x4 I2C LCD | 1 | $9.99 | https://www.amazon.com/GeeekPi-Interface-Adapter-Backlight-Raspberry/dp/B07QLRD3TM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
Rotary Encoder | 1 (2 pack) | $6.99 | https://www.amazon.com/JTAREA-KY-040-Encoder-Encoders-Modules/dp/B0D2TTG858?s=electronics
V-Slot Screws | 1 (180pcs) | $12.99 | https://www.amazon.com/Rrina-Assortment-European-Standard-Aluminum/dp/B0BZP8T639
Stepper Motor Drivers | 4 (5 pack) | $10.19 | https://www.amazon.com/HiLetgo-Stepstick-Stepper-Printer-Compatible/dp/B07BND65C8?s=electronics
Nema 17 Stepper Motor | 1 | $7.99 | https://www.amazon.com/Usongshine-Stepper-17HS4401S-Connector-Printer/dp/B0787BQ4WH
5015 Blower Fan | 1 (2 pack) | $5.99 | https://www.amazon.com/Usongshine-Stepper-17HS4401S-Connector-Printer/dp/B0787BQ4WH
120mm PC Fan | 1 | $9.48 | https://www.amazon.com/ARCTIC-ACFAN00119A-P12-Black-Pressure-Optimized/dp/B07GB5JRTZ?s=industrial
Diaphragm Pumps | 4 | $67.92 | https://www.amazon.com/Gikfun-DC-Self-priming-Diaphragm-Dispenser/dp/B09ZX4TFNG?ref_=ast_sto_dp
Relay Modules | 2 | $15.98 | https://www.amazon.com/SunFounder-Channel-Shield-Arduino-Raspberry/dp/B00E0NSORY?s=industrial
5*8 Tubing | 1 | $14.59 | https://www.amazon.com/dp/B07WFHS6PM?th=1
Buck Converters | 2 (3 pack) | $9.98 | https://www.amazon.com/Stemedu-Converter-Adjustable-Regulator-Step-Down/dp/B0BTBVDB4S
12v motor | 1 | $14.99 | https://www.amazon.com/Greartisan-Electric-Reduction-Eccentric-Diameter/dp/B071XCX778?s=industrial
5v motors | 2 (3 pack) | $6.79 | https://www.amazon.com/dp/B0D6DR31TS?th=1
3v vibration motor | 1 (2 pack) | $8.99 | https://www.amazon.com/BOJACK-Vibration-Powerful-Electric-Vibrating/dp/B09XDWPMHY?s=industrial
LED Strips | 1 | $27.99 | https://www.amazon.com/BTF-LIGHTING-WS2812B5M60LB30-BTF-LIGHTING-WS2812B-IC-RGB-5050SMD-Pure-Gold-Individual-Addressable-LED-Strip-High-Quality-16-4FT-300LED-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
Black Filament | 2 | $27.59 | https://www.amazon.com/OVERTURE-Filament-Consumables-Dimensional-Accuracy/dp/B07PGY2JP1?s=industrial
White Filament | 1 | $16.98 | https://www.amazon.com/OVERTURE-Filament-Consumables-Dimensional-Accuracy/dp/B07PGZNM34?s=industrial
Gold Filament | 1 | $21.59 | https://www.amazon.com/OVERTURE-Filament-Consumables-Dimensional-Accuracy/dp/B08N4H6T54?s=industrial
12mm Buttons | 3 (70pcs) | $8.99 | https://www.amazon.com/TWTADE-Momentary-Tactile-Button-12x12x12mm/dp/B07CG7VTGD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
Cable Chains | 2 | $9.98 | https://www.amazon.com/LMioEtool-Plastic-Carrier-Length-Connectors/dp/B07QVKL9VL?s=industrial
Assorted Wires | lots | $15.29 | https://www.amazon.com/TUOFENG-Hookup-Wires-6-Different-Colored/dp/B07TX6BX47?s=industrial
220 Ohm Resistors | 5 (1000pcs) | $9.99 | https://www.amazon.com/BOJACK-Values-Resistor-Resistors-Assortment/dp/B08FD1XVL6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
Zipties | lots | $5.99 | https://www.amazon.com/Assorted-Sizes-12-Resistant-ANOSON/dp/B0C2Z4L3S6?sp_csd=d2lkZ2V0TmFtZT1zcF9hdGY
Pitchers | 3 | $17.97 | https://www.amazon.com/Unbreakable-Lemonade-Beverage-Dispenser-Airtight/dp/B0F2FFVNZC
FOOD/OTHER:
Boba Kits | 1 (depends on demand) | $19.98 | https://www.amazon.com/dp/B0DGV6JHVJ/ref=twister_B0DK3ZSR6J?_encoding=UTF8&th=1
Milk | 1 (depends on demand) | $3.99 | Walmart
12oz Cups | 100 | $26.99 | https://www.amazon.com/Plastic-Disposable-Drinking-Smoothie-Frappuccino/dp/B09MD1Q5YS
Straws | 100 | $9.99 | https://www.amazon.com/MYJIE-Individually-Disposable-Wide-mouthed-Milkshake/dp/B09C7KNSJX

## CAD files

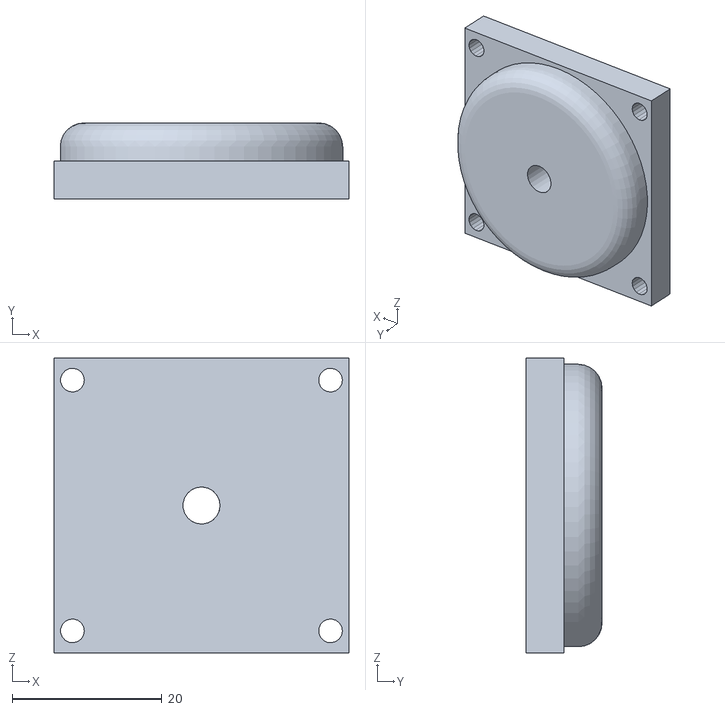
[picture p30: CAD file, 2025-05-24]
3D Models/.stl Files/WhiteofEyeAssembly.stl
39.4 x 10.2 x 39.4

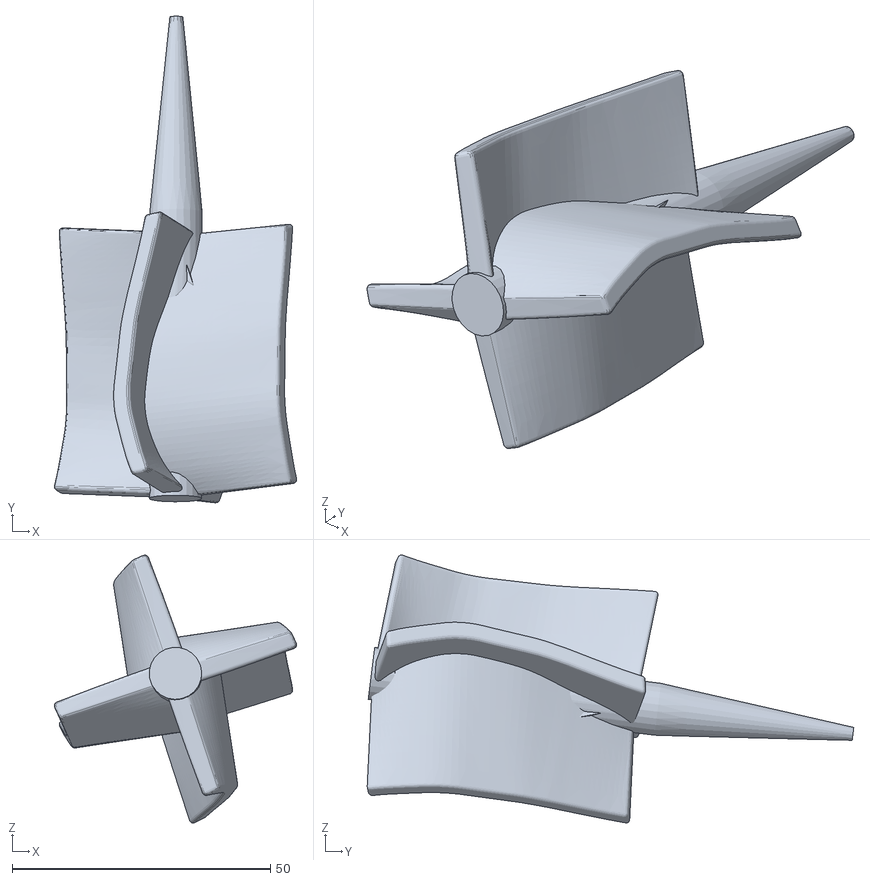
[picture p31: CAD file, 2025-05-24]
3D Models/.stl Files/Mixer_1.stl
46.9 x 94.2 x 51.9

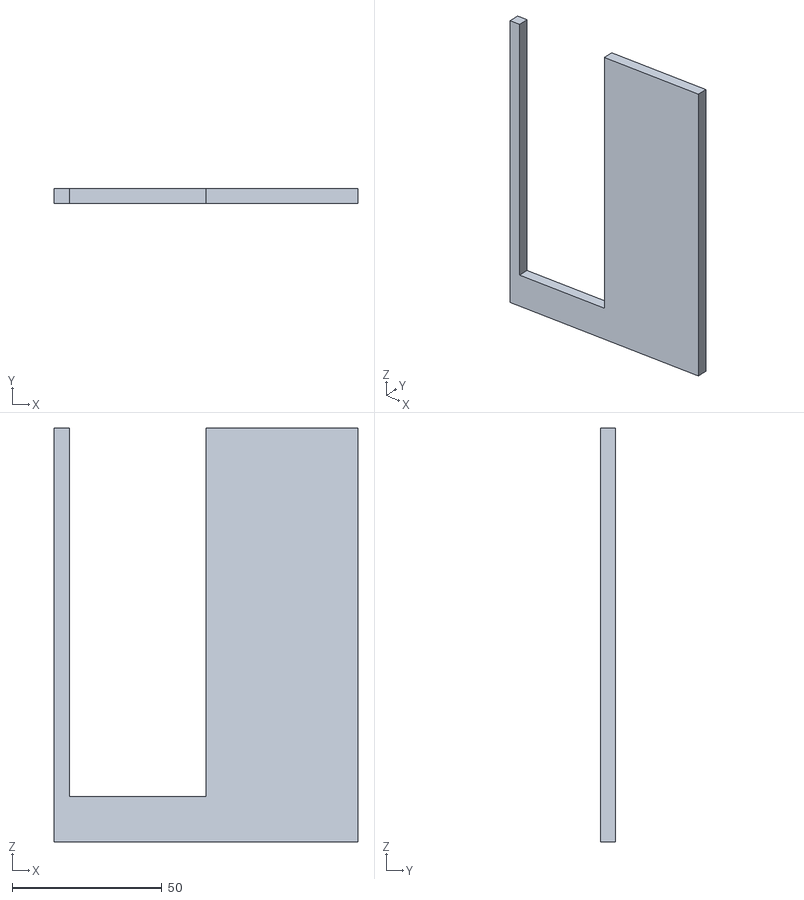
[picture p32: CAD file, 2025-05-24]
3D Models/.stl Files/NewTop v2.stl
101.6 x 5.08 x 138.4

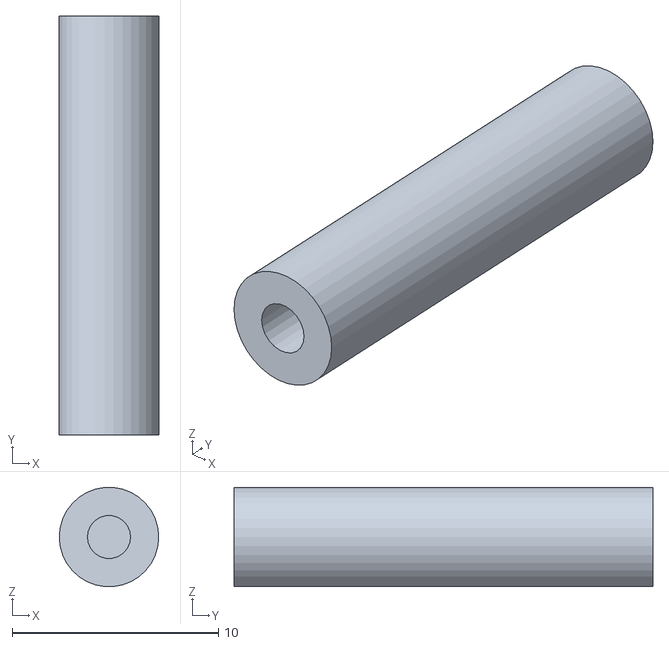
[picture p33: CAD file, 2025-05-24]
3D Models/.stl Files/Motor_shaft_1.stl
4.83 x 20.3 x 4.81

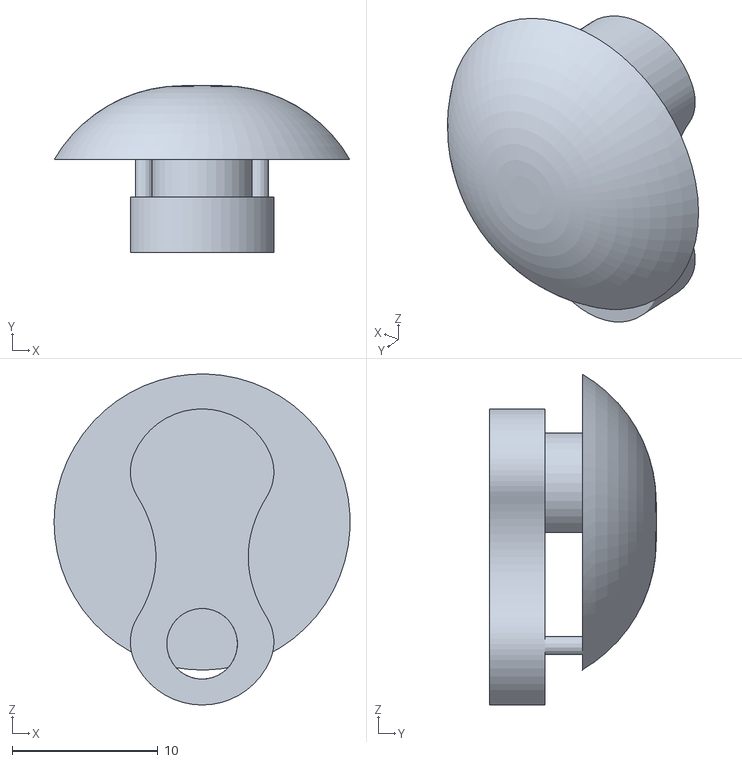
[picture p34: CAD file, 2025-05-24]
3D Models/.stl Files/PupilandAttachment.stl
20.3 x 11.4 x 22.7

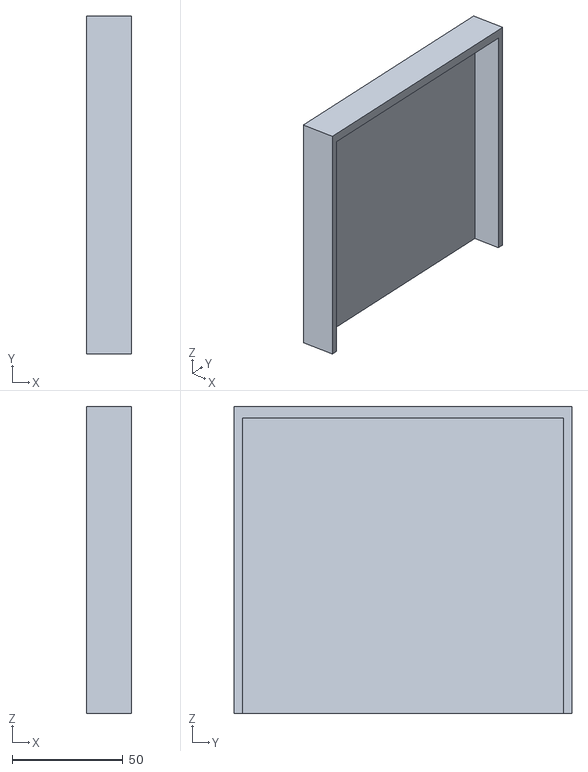
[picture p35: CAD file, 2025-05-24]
3D Models/.stl Files/disguising the ugly.stl
20.3 x 152.4 x 138.4

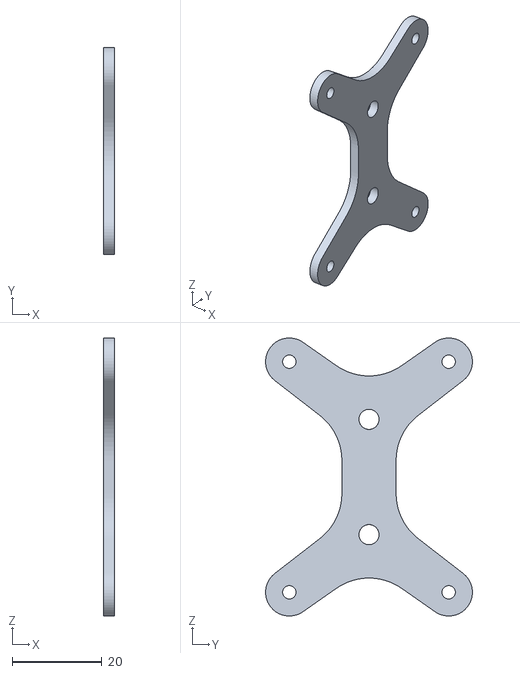
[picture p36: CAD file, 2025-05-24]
3D Models/.stl Files/pump mount.stl
2.54 x 46.2 x 62.1

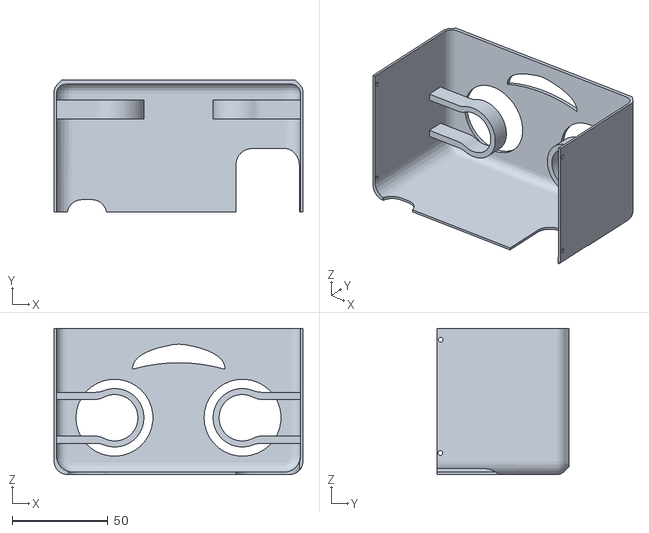
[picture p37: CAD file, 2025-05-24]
3D Models/.stl Files/New Mixer Cover 2.stl
129.8 x 68.6 x 76.2

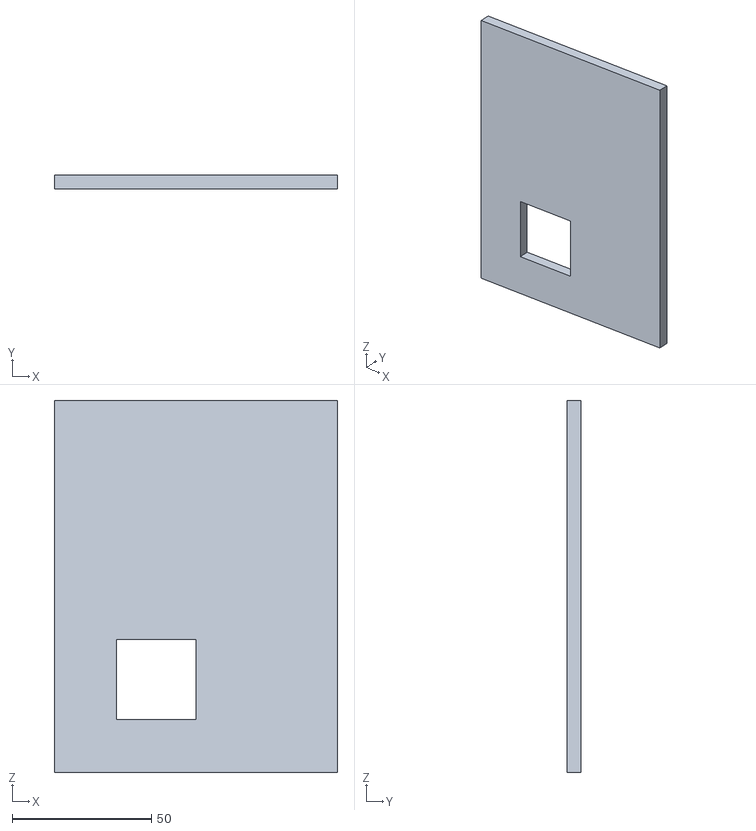
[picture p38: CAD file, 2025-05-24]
3D Models/.stl Files/HalfofTop.stl
101.6 x 5.08 x 133.4

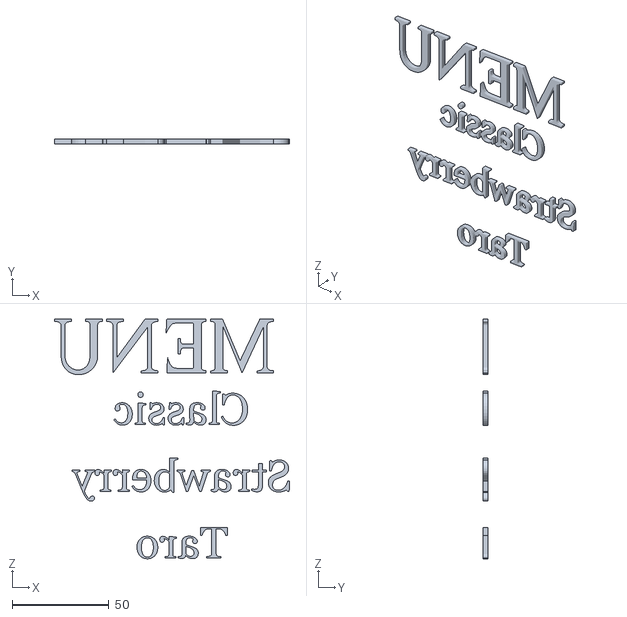
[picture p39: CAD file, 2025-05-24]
3D Models/.stl Files/Menu words.stl
121.7 x 2.54 x 124.1

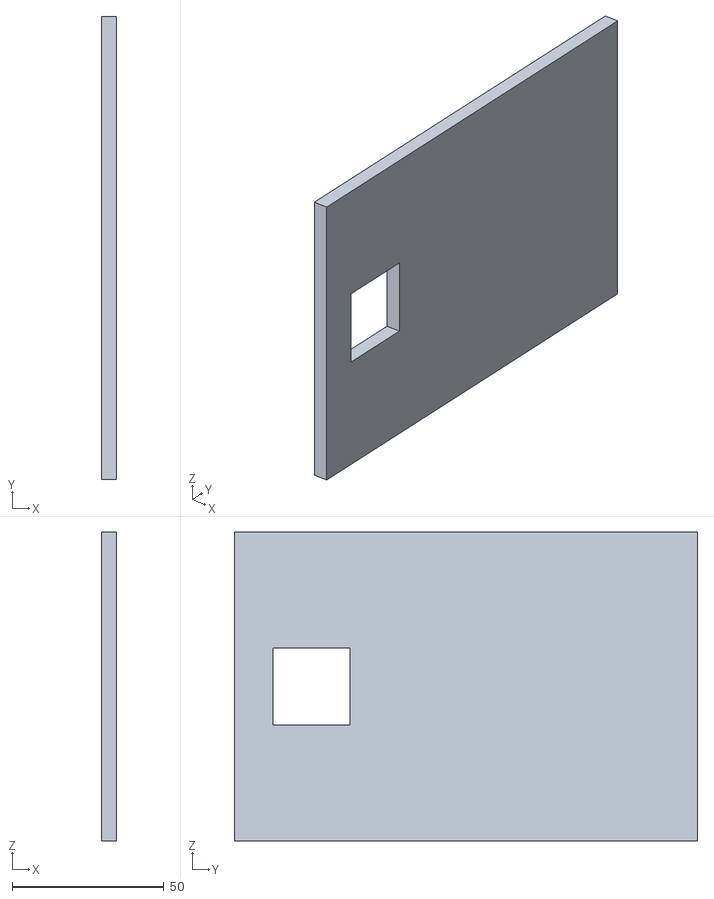
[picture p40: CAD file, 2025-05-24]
3D Models/.stl Files/Left wall.stl
5.08 x 152.4 x 101.6

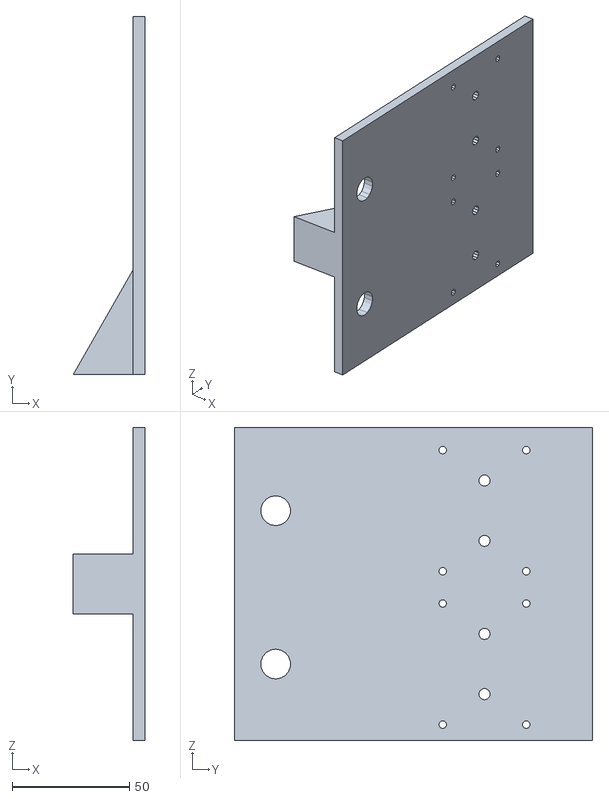
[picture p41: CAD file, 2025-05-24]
3D Models/.stl Files/HalfBackWall.stl
30.5 x 152.4 x 133.4

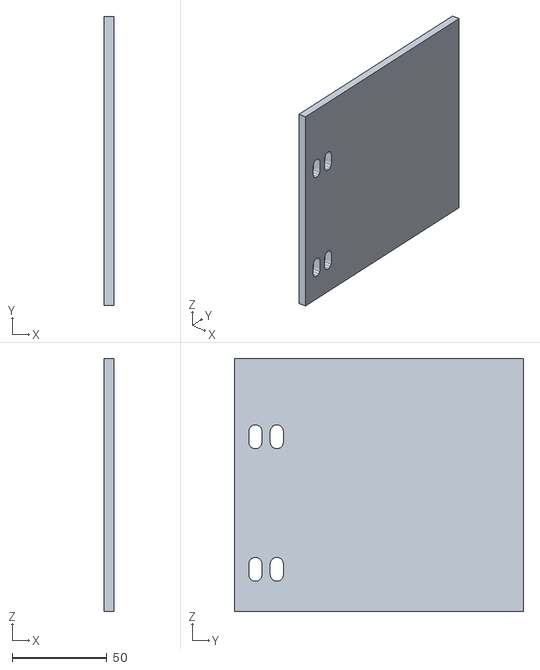
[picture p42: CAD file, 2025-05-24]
3D Models/.stl Files/HalfFrontWall.stl
5.08 x 152.4 x 133.4

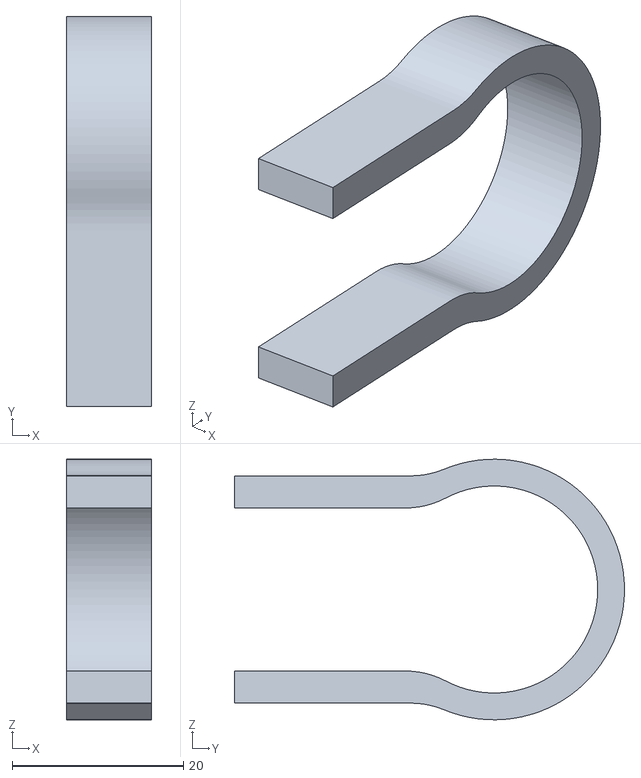
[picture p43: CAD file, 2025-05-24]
3D Models/.stl Files/eye motor holder2.stl
9.91 x 45.6 x 30.5

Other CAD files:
3D Models/.stl Files/Cup Holder for Bubba.stl
3D Models/.stl Files/Mixer and nozzle cover copy.stl
3D Models/.stl Files/Boba decor.stl
3D Models/.stl Files/SecondHalfofTop.stl
3D Models/.iam Files/Boba Dispenser/Boba Dispenser 3.iam
3D Models/.iam Files/Boba Dispenser/Boba Funnel Top 2.ipt
3D Models/.iam Files/Boba Dispenser/Boba dispenser 3 bottom.ipt
3D Models/.iam Files/Boba Dispenser/Boba dispenser 3 top.ipt
3D Models/.iam Files/Boba Dispenser/Dispenser Tip.ipt
3D Models/.iam Files/Boba Dispenser/SERVO SBORKA.iam
3D Models/.iam Files/Boba Dispenser/SPHERE_candies.ipt
3D Models/.iam Files/Boba Dispenser/accum cap.ipt
3D Models/.iam Files/Boba Dispenser/adapter2.ipt
3D Models/.iam Files/Boba Dispenser/angular contact ball bearing_68_iso_ISO 15 ABB - 2915 - 14,SI,NC,14_68.ipt
3D Models/.iam Files/Boba Dispenser/assembled bank.iam
3D Models/.iam Files/Boba Dispenser/auger.ipt
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

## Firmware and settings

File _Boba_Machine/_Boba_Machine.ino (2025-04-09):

#include <AccelStepper.h>
#include <Servo.h>
#include <LiquidCrystal_I2C.h>
#include <SPI.h>
#include <MFRC522.h>
#include <Adafruit_NeoPixel.h>
#include <avr/wdt.h>

// ==== Constants and Pins ====
#define I2C_ADDR 0x27
#define LCD_COLUMNS 20
#define LCD_LINES 4
LiquidCrystal_I2C lcd(I2C_ADDR, LCD_COLUMNS, LCD_LINES);

#define SS_PIN 10
#define RST_PIN 9
MFRC522 mfrc522(SS_PIN, RST_PIN);

#define LED_STRIP_PIN 30
#define NUMPIXELS 200
Adafruit_NeoPixel pixels = Adafruit_NeoPixel(NUMPIXELS, LED_STRIP_PIN, NEO_GRB + NEO_KHZ800);

#define ENCODER_CLK 49
#define ENCODER_DT 51
#define ENCODER_SW 53
#define RESET_BUTTON_PIN 6
#define LIMIT_SWITCH_PIN A7

Servo servo_A0;

// Stepper Motors
AccelStepper stepper1(1, 13, 12);
AccelStepper stepper2(1, 11, 10);
AccelStepper stepper3(1, 9, 8);
AccelStepper stepper4(1, 7, 6);

// ==== Global Variables ====
int milkRatio = 60, flavorRatio = 20, bobaRatio = 20;
int redColor = 0, greenColor = 0, blueColor = 0;
int currentBrightness = 51;
bool isAllowed = false;
int lastStateCLK, lastLimitValue = -1;
bool buttonPressed = false;
bool inDrinkMenu = true;
int menuIndex = 0, menuStartIndex = 0;

void waitForCupGrab(); // ← add this near the top, under your global variables

String drinkMenu[] = { "Brown Sugar Tea", "Strawberry Milk", "Taro Milk Tea", "Back to Control" };
int drinkMenuSize = sizeof(drinkMenu) / sizeof(drinkMenu[0]);

String controlMenu[] = { "Run Diagnostics", "RFID Access", "Servo Trigger", "Manual Axis Ctrl", "LED Settings", "Reset System" };
int controlMenuSize = sizeof(controlMenu) / sizeof(controlMenu[0]);

void setup() {
  Serial.begin(9600);
  lcd.init(); lcd.backlight();
  lcd.setCursor(3, 1); lcd.print("YUMMY BOBA BOT");
  delay(1500);

  for (int i = 1; i <= 4; i++) {
    AccelStepper* s = (i == 1) ? &stepper1 : (i == 2) ? &stepper2 : (i == 3) ? &stepper3 : &stepper4;
    s->setMaxSpeed(1000); s->setAcceleration(1000); s->setCurrentPosition(0);
  }

  pinMode(ENCODER_CLK, INPUT);
  pinMode(ENCODER_DT, INPUT);
  pinMode(ENCODER_SW, INPUT_PULLUP);
  pinMode(RESET_BUTTON_PIN, INPUT_PULLUP);
  lastStateCLK = digitalRead(ENCODER_CLK);

  SPI.begin();
  mfrc522.PCD_Init();

  servo_A0.attach(A0, 500, 2500); servo_A0.write(0); delay(500); servo_A0.detach();

  pixels.begin();
  pixels.setBrightness(currentBrightness);
  pixels.clear(); pixels.show();

  performHoming();
  showDrinkMenu();
}

void loop() {
  handleRotaryEncoder();

  if (digitalRead(ENCODER_SW) == LOW && !buttonPressed) {
    buttonPressed = true;
    selectMenuItem();
  } else if (digitalRead(ENCODER_SW) == HIGH) {
    buttonPressed = false;
  }

  if (digitalRead(RESET_BUTTON_PIN) == LOW) {
    lcd.clear(); lcd.print("System Reset...");
    delay(1000);
    wdt_enable(WDTO_15MS); while (1) {}
  }

  int currentLimitValue = analogRead(LIMIT_SWITCH_PIN);
  if (currentLimitValue != lastLimitValue) {
    Serial.print("Analog Read A7 = "); Serial.println(currentLimitValue);
    lastLimitValue = currentLimitValue;
  }
}

void performHoming() {
  lcd.clear(); lcd.print("Homing in progress");

  // HOMING STEPPER 1 (X AXIS)
  stepper1.setMaxSpeed(5000.0);
  stepper1.setAcceleration(1000.0);
  Serial.println("Stepper 1 is Homing");
  while (digitalRead(4) != HIGH) { // Using Pin 4 for Stepper 1 Limit Switch
    stepper1.moveTo(stepper1.currentPosition() + 1);
    stepper1.run();
    delay(5);
  }
  stepper1.setCurrentPosition(0);
  Serial.println("Homing 1 Completed");

  // HOMING STEPPER 4 (CUP SLIDE AXIS)
  stepper4.setMaxSpeed(5000.0);
  stepper4.setAcceleration(1000.0);
  Serial.println("Stepper 2 is Homing");
  while (digitalRead(2) != HIGH) { // Using Pin 2 for Stepper 4 Limit Switch
    stepper4.moveTo(stepper4.currentPosition() - 1);
    stepper4.run();
    delay(5);
  }
  stepper4.setCurrentPosition(0);
  Serial.println("Homing 2 Completed");

  // HOMING STEPPER 3 (Z AXIS)
  stepper3.setMaxSpeed(5000.0);
  stepper3.setAcceleration(1000.0);
  Serial.println("Stepper 3 is Homing");
  while (digitalRead(3) != HIGH) { // Using Pin 3 for Stepper 3 Limit Switch
    stepper3.moveTo(stepper3.currentPosition() - 1);
    stepper3.run();
    delay(5);
  }
  stepper3.setCurrentPosition(0);
  Serial.println("Homing 3 Completed");

  // HOMING COMPLETE
  lcd.setCursor(0, 1); lcd.print("Homing Complete");
  Serial.println("Full Homing Sequence Completed");
  delay(1500);
}

void handleRotaryEncoder() {
  int currentStateCLK = digitalRead(ENCODER_CLK);
  if (currentStateCLK != lastStateCLK) {
    if (digitalRead(ENCODER_DT) != currentStateCLK) menuIndex++;
    else menuIndex--;

    int currentSize = inDrinkMenu ? drinkMenuSize : controlMenuSize;
    if (menuIndex >= currentSize) menuIndex = 0;
    if (menuIndex < 0) menuIndex = currentSize - 1;

    if (menuIndex >= menuStartIndex + 3) menuStartIndex++;
    else if (menuIndex < menuStartIndex) menuStartIndex--;

    updateMenuDisplay();
  }
  lastStateCLK = currentStateCLK;
}

void updateMenuDisplay() {
  lcd.clear();
  lcd.setCursor(0, 0);
  lcd.print(inDrinkMenu ? "Drinks Menu:" : "Control Menu:");
  for (int i = 0; i < 3; i++) {
    int itemIndex = menuStartIndex + i;
    if (itemIndex < (inDrinkMenu ? drinkMenuSize : controlMenuSize)) {
      lcd.setCursor(1, i + 1);
      lcd.print((itemIndex == menuIndex) ? "> " : "  ");
      lcd.print(inDrinkMenu ? drinkMenu[itemIndex] : controlMenu[itemIndex]);
    }
  }
}

void showDrinkMenu() {
  inDrinkMenu = true;
  menuIndex = 0;
  menuStartIndex = 0;
  updateMenuDisplay();
}

void showControlMenu() {
  inDrinkMenu = false;
  menuIndex = 0;
  menuStartIndex = 0;
  updateMenuDisplay();
}
void selectMenuItem() {
  lcd.clear(); lcd.setCursor(0, 0); lcd.print("Selected:");
  lcd.setCursor(2, 2); lcd.print(inDrinkMenu ? drinkMenu[menuIndex] : controlMenu[menuIndex]);
  delay(1000);

  if (inDrinkMenu) {
    if (drinkMenu[menuIndex] == "Back to Control") {
      showControlMenu();
    } else {
      askBobaPreference();
    }
  } else {
    String selected = controlMenu[menuIndex];
    if (selected == "Reset System") {
      performHoming();
      showDrinkMenu();
    } else if (selected == "Manual Axis Ctrl") {
      manualAxisControl();
    } else if (selected == "LED Settings") {
      ledControl();
    } else if (selected == "RFID Access") {
      checkRFID();
    } else if (selected == "Servo Trigger") {
      servoControl();
    } else if (selected == "Run Diagnostics") {
      runDiagnostics();
    }
  }

  updateMenuDisplay();
}
void askBobaPreference() {
  bool addBoba = true, addSyrup = false;
  bool confirmed = false;

  while (!confirmed) {
    lcd.clear(); lcd.setCursor(0, 0); lcd.print("Add Boba?");
    lcd.setCursor(2, 2); lcd.print(addBoba ? "Yes" : "No");
    int clk = digitalRead(ENCODER_CLK);
    if (clk != lastStateCLK) addBoba = !addBoba;
    lastStateCLK = clk;
    if (digitalRead(ENCODER_SW) == LOW) { confirmed = true; delay(300); }
  }

  if (addBoba) adjustBobaPercentage();
  else bobaRatio = 0;

  confirmed = false;
  while (!confirmed) {
    lcd.clear(); lcd.setCursor(0, 0); lcd.print("Add Syrup Ring?");
    lcd.setCursor(2, 2); lcd.print(addSyrup ? "Yes" : "No");
    int clk = digitalRead(ENCODER_CLK);
    if (clk != lastStateCLK) addSyrup = !addSyrup;
    lastStateCLK = clk;
    if (digitalRead(ENCODER_SW) == LOW) { confirmed = true; delay(300); }
  }

  lcd.clear(); lcd.print("Creating drink...");
  delay(1500);
  startDrinkMakingProcess(addSyrup);
}

void adjustBobaPercentage() {
  int percentage = bobaRatio;
  while (true) {
    lcd.clear(); lcd.setCursor(0, 0); lcd.print("Set Boba Amount");
    lcd.setCursor(2, 2); lcd.print(percentage); lcd.print("%");

    int clk = digitalRead(ENCODER_CLK);
    if (clk != lastStateCLK) {
      percentage += (digitalRead(ENCODER_DT) != clk) ? 5 : -5;
      percentage = constrain(percentage, 0, 100);
    }
    lastStateCLK = clk;
    if (digitalRead(ENCODER_SW) == LOW) {
      bobaRatio = percentage;
      delay(300);
      break;
    }
  }
}
void startDrinkMakingProcess(bool addSyrup) {
  slideCupOut();
  waitForCupGrab();
  returnCupToCenter();
  if (addSyrup) applySyrupRing();
  dispenseMilk();
  dispenseFlavor();
  mixDrink();
  if (bobaRatio > 0) { moveToBoba(); dispenseBoba(); }
  liftCup();
  presentCupToUser();
  waitToStartNewOrder();
}

void slideCupOut() {
  lcd.clear(); lcd.print("Sliding cup out...");
  stepper4.moveTo(1000); // Slide out
  while (stepper4.distanceToGo() != 0) stepper4.run();
  delay(500);
}

void returnCupToCenter() {
  lcd.clear(); lcd.print("Returning cup...");
  stepper4.moveTo(0); // Return to center
  while (stepper4.distanceToGo() != 0) stepper4.run();
  delay(500);
}

void applySyrupRing() {
  lcd.clear(); lcd.print("Applying syrup...");
  stepper1.moveTo(500); // Move to syrup zone
  while (stepper1.distanceToGo() != 0) stepper1.run();
  delay(500);
  stepper1.moveTo(0); // Return
  while (stepper1.distanceToGo() != 0) stepper1.run();
  delay(500);
}

void dispenseMilk() {
  lcd.clear(); lcd.print("Dispensing Milk");
  lcd.setCursor(0, 2); lcd.print(milkRatio); lcd.print("%");
  stepper2.moveTo(milkRatio * 10); // Simulate pump
  while (stepper2.distanceToGo() != 0) stepper2.run();
  delay(500);
  stepper2.moveTo(0);
  while (stepper2.distanceToGo() != 0) stepper2.run();
  delay(300);
}

void dispenseFlavor() {
  lcd.clear(); lcd.print("Adding Flavor");
  lcd.setCursor(0, 2); lcd.print(flavorRatio); lcd.print("%");
  stepper2.moveTo(flavorRatio * 10);
  while (stepper2.distanceToGo() != 0) stepper2.run();
  delay(500);
  stepper2.moveTo(0);
  while (stepper2.distanceToGo() != 0) stepper2.run();
  delay(300);
}

void mixDrink() {
  lcd.clear(); lcd.print("Mixing drink...");
  stepper3.moveTo(500); // Lower + spin
  while (stepper3.distanceToGo() != 0) stepper3.run();
  delay(500);
  stepper3.moveTo(0); // Return
  while (stepper3.distanceToGo() != 0) stepper3.run();
  delay(500);
}

void moveToBoba() {
  lcd.clear(); lcd.print("Positioning Boba");
  stepper1.moveTo(1000); // Move under boba
  while (stepper1.distanceToGo() != 0) stepper1.run();
  delay(500);
}

void dispenseBoba() {
  lcd.clear(); lcd.print("Dispensing Boba");
  stepper2.moveTo(bobaRatio * 10);
  while (stepper2.distanceToGo() != 0) stepper2.run();
  delay(500);
  stepper2.moveTo(0);
  while (stepper2.distanceToGo() != 0) stepper2.run();
  delay(500);
}

void liftCup() {
  lcd.clear(); lcd.print("Raising mixer...");
  stepper3.moveTo(300); // Raise
  while (stepper3.distanceToGo() != 0) stepper3.run();
  delay(500);
  stepper3.moveTo(0);
  while (stepper3.distanceToGo() != 0) stepper3.run();
  delay(500);
}

void presentCupToUser() {
  lcd.clear(); lcd.print("Slide out cup");
  lcd.setCursor(0, 1); lcd.print("Grab & Press Btn");
  stepper4.moveTo(1000); // Slide cup out again
  while (stepper4.distanceToGo() != 0) stepper4.run();
  while (digitalRead(ENCODER_SW) == HIGH) delay(10);
  lcd.clear(); lcd.print("Cup retrieved!");
  delay(1000);
  stepper4.moveTo(0); // Pull tray back in
  while (stepper4.distanceToGo() != 0) stepper4.run();
  delay(500);
}

void waitToStartNewOrder() {
  lcd.clear(); lcd.print("Start another?");
  lcd.setCursor(0, 2); lcd.print("Press button...");
  while (digitalRead(ENCODER_SW) == HIGH) delay(10);
  lcd.clear(); lcd.print("Resetting system...");
  delay(1000);
  performHoming();
  showDrinkMenu();
}
void manualAxisControl() {
  int axisIndex = 0;
  bool selecting = true;

  while (selecting) {
    lcd.clear();
    lcd.setCursor(0, 0); lcd.print("Manual Axis Ctrl:");
    lcd.setCursor(1, 1); lcd.print(axisIndex == 0 ? "> X Axis" : "  X Axis");
    lcd.setCursor(1, 2); lcd.print(axisIndex == 1 ? "> Y Axis" : "  Y Axis");
    lcd.setCursor(1, 3); lcd.print(axisIndex == 2 ? "> Z Axis" : "  Z Axis");

    int currentStateCLK = digitalRead(ENCODER_CLK);
    if (currentStateCLK != lastStateCLK) {
      axisIndex += (digitalRead(ENCODER_DT) != currentStateCLK) ? 1 : -1;
      if (axisIndex > 2) axisIndex = 0;
      if (axisIndex < 0) axisIndex = 2;
    }
    lastStateCLK = currentStateCLK;

    if (digitalRead(ENCODER_SW) == LOW) {
      delay(300);
      controlAxis(axisIndex);
      selecting = false;
    }
  }
}

void controlAxis(int axis) {
  AccelStepper* selected = (axis == 0) ? &stepper1 : (axis == 1) ? &stepper2 : &stepper3;
  long position = 0;

  lcd.clear(); lcd.print("Move Axis:");
  while (true) {
    int currentStateCLK = digitalRead(ENCODER_CLK);
    if (currentStateCLK != lastStateCLK) {
      position += (digitalRead(ENCODER_DT) != currentStateCLK) ? 10 : -10;
      selected->moveTo(position);
    }
    selected->run();
    lastStateCLK = currentStateCLK;

    if (digitalRead(ENCODER_SW) == LOW) break;
  }

  lcd.clear(); lcd.print("Axis Movement Done");
  delay(1000);
}

void ledControl() {
  int choice = 0;
  while (true) {
    lcd.clear(); lcd.setCursor(0, 0); lcd.print("LED Control:");
    lcd.setCursor(1, 1); lcd.print(choice == 0 ? "> Brightness" : "  Brightness");
    lcd.setCursor(1, 2); lcd.print(choice == 1 ? "> Color" : "  Color");

    int clk = digitalRead(ENCODER_CLK);
    if (clk != lastStateCLK) {
      choice += (digitalRead(ENCODER_DT) != clk) ? 1 : -1;
      if (choice > 1) choice = 0;
      if (choice < 0) choice = 1;
    }
    lastStateCLK = clk;

    if (digitalRead(ENCODER_SW) == LOW) {
      delay(300);
      if (choice == 0) adjustBrightness();
      else changeColor();
      break;
    }
  }
}

void adjustBrightness() {
  int brightnessValue = currentBrightness;
  while (true) {
    int clk = digitalRead(ENCODER_CLK);
    if (clk != lastStateCLK) {
      brightnessValue += (digitalRead(ENCODER_DT) != clk) ? 5 : -5;
      brightnessValue = constrain(brightnessValue, 0, 255);
      currentBrightness = brightnessValue;
      pixels.setBrightness(currentBrightness);
      pixels.show();
      lcd.clear(); lcd.print("Brightness: "); lcd.print(currentBrightness);
    }
    lastStateCLK = clk;
    if (digitalRead(ENCODER_SW) == LOW) break;
  }
  delay(300);
}

void changeColor() {
  redColor = random(0, 255);
  greenColor = random(0, 255);
  blueColor = random(0, 255);
  for (int i = 0; i < NUMPIXELS; i++) {
    pixels.setPixelColor(i, pixels.Color(redColor, greenColor, blueColor));
  }
  pixels.setBrightness(currentBrightness);
  pixels.show();
  lcd.clear(); lcd.print("New Color Set");
  delay(1500);
}

void checkRFID() {
  lcd.clear(); lcd.print("Scan Card...");
  while (true) {
    if (!mfrc522.PICC_IsNewCardPresent() || !mfrc522.PICC_ReadCardSerial()) continue;
    String content = "";
    for (byte i = 0; i < mfrc522.uid.size; i++) {
      content.concat(String(mfrc522.uid.uidByte[i], HEX));
    }
    content.toUpperCase();
    lcd.clear();

    if (content == "87E5BEA7" || content == "EAFA9C82") {
      lcd.print("Access Granted");
      isAllowed = true;
      flashColor(0, 255, 0);
    } else {
      lcd.print("Access Denied");
      isAllowed = false;
      flashColor(255, 0, 0);
    }

    delay(2000);
    for (int i = 0; i < NUMPIXELS; i++) pixels.setPixelColor(i, pixels.Color(255, 255, 255));
    pixels.show();
    break;
  }
}

void flashColor(uint8_t r, uint8_t g, uint8_t b) {
  for (int i = 0; i < 3; i++) {
    for (int j = 0; j < NUMPIXELS; j++) {
      pixels.setPixelColor(j, pixels.Color(r, g, b));
    }
    pixels.show();
    delay(300);
    for (int j = 0; j < NUMPIXELS; j++) {
      pixels.setPixelColor(j, 0);
    }
    pixels.show();
    delay(300);
  }
}

void servoControl() {
  lcd.clear(); lcd.print("Servo Triggering");
  servo_A0.attach(A0, 500, 2500);
  servo_A0.write(90);
  delay(1000);
  servo_A0.write(0);
  delay(500);
  servo_A0.detach();
  lcd.setCursor(0, 1); lcd.print("Reset Complete");
  delay(1000);
}

void runDiagnostics() {
  lcd.clear(); lcd.print("Running Tests...");
  Serial.println("Stepper Homing Starting");
  performHoming();
  Serial.println("Diagnostics Complete");
  lcd.setCursor(0, 1); lcd.print("Diagnostics OK");
  delay(1500);
}

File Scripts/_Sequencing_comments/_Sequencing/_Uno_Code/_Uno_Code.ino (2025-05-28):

#include <AccelStepper.h>
#include <Servo.h>

// === Stepper Motors ===
AccelStepper stepperX(1, 13, 12); // X axis
AccelStepper stepperZ(1, 11, 10); // Z axis
AccelStepper stepperY(1, 7, 6);   // Y axis
AccelStepper stepper3(AccelStepper::DRIVER, 9, 8); // Boba Dispenser

#define STEPS_PER_REV 200

// === Limit Switches ===
#define LIMIT_X 4
#define LIMIT_Y 2
#define LIMIT_Z 3

// === Relays (Updated Pins) ===
#define RELAY_MIXER A2
#define RELAY_BOBA_SHAKER A3

Servo coverServo;

void setup() {
 Serial.begin(9600);

 // Slower and smoother speeds
 stepperX.setMaxSpeed(2000);
 stepperX.setAcceleration(2000);
 stepperY.setMaxSpeed(2000);
 stepperY.setAcceleration(800);
 stepperZ.setMaxSpeed(2000);
 stepperZ.setAcceleration(2000);
 stepper3.setMaxSpeed(800);
 stepper3.setAcceleration(300);

 stepperX.setCurrentPosition(0);
 stepperY.setCurrentPosition(0);
 stepperZ.setCurrentPosition(0);
 stepper3.setCurrentPosition(0);

 pinMode(LIMIT_X, INPUT_PULLUP);
 pinMode(LIMIT_Y, INPUT_PULLUP);
 pinMode(LIMIT_Z, INPUT_PULLUP);

 pinMode(RELAY_MIXER, OUTPUT);
 pinMode(RELAY_BOBA_SHAKER, OUTPUT);
 digitalWrite(RELAY_MIXER, LOW);
 digitalWrite(RELAY_BOBA_SHAKER, LOW);

 coverServo.attach(A1);
 coverServo.write(0);

 Serial.println("== SYSTEM STARTING ==");
}

void loop() {
 runFullSequence();
}

// === HOMING ===
void homeAllMotors() {
 delay(3000);

  Serial.println("Fast homing Z...");
 stepperZ.setSpeed(-400);
 while (digitalRead(LIMIT_Z) != HIGH) {
   stepperZ.runSpeed();
 }
 stepperZ.setCurrentPosition(0);
 Serial.println("Z homed");

 Serial.println("Fast homing X...");
 stepperX.setSpeed(400);
 while (digitalRead(LIMIT_X) != HIGH) {
   stepperX.runSpeed();
 }
 stepperX.setCurrentPosition(0);
 Serial.println("X homed");

 Serial.println("Fast homing Y...");
 stepperY.setSpeed(-400);
 while (digitalRead(LIMIT_Y) != HIGH) {
   stepperY.runSpeed();
 }
 stepperY.setCurrentPosition(0);
 Serial.println("Y homed");

 delay(100);
}

// === Full Drink Routine ===
void runFullSequence() {
 homeAllMotors();

 stepperZ.setMaxSpeed(1000); 
 stepperZ.setAcceleration(1000);  

 // Y slides out
 stepperY.moveTo(1100);
 stepperY.runToPosition();
 Serial.println("Y extended for cup");

 // Wait for photoresistor signal (light)
 waitForSignal();

 // Y slides in
 stepperY.moveTo(560);
 stepperY.runToPosition();
 Serial.println("Y pulled cup in");

  // X moves to tubes
 stepperX.moveTo(-260);
 stepperX.runToPosition();
 Serial.println("X moved to tubes");
 
  // Z lowers
 stepperZ.moveTo(2000);
 stepperZ.runToPosition();
 Serial.println("Z lowered");

 delay(21000);  // Dispensing flavor

   // X oscilation
    stepperX.setMaxSpeed(5000); 
 stepperX.setAcceleration(5000);  
 stepperX.moveTo(-250);
 stepperX.runToPosition();
  stepperX.moveTo(-260);
 stepperX.runToPosition();
  stepperX.moveTo(-250);
 stepperX.runToPosition();
  stepperX.moveTo(-260);
 stepperX.runToPosition();
  stepperX.moveTo(-250);
 stepperX.runToPosition();
  stepperX.moveTo(-260);
 stepperX.runToPosition();
  stepperX.moveTo(-250);
 stepperX.runToPosition();
  stepperX.moveTo(-260);
 stepperX.runToPosition();
  stepperX.moveTo(-250);
 stepperX.runToPosition();
  stepperX.moveTo(-260);
 stepperX.runToPosition();
  stepperX.moveTo(-250);
 stepperX.runToPosition();
  stepperX.moveTo(-260);
 stepperX.runToPosition();
  stepperX.moveTo(-250);
 stepperX.runToPosition();
  stepperX.moveTo(-260);
 stepperX.runToPosition();
  stepperX.moveTo(-250);
 stepperX.runToPosition();
  stepperX.moveTo(-260);
 stepperX.runToPosition();
   stepperX.moveTo(-250);
 stepperX.runToPosition();
  stepperX.moveTo(-260);
 stepperX.runToPosition();
   stepperX.moveTo(-250);
 stepperX.runToPosition();
  stepperX.moveTo(-260);
 stepperX.runToPosition();
   stepperX.moveTo(-250);
 stepperX.runToPosition();
  stepperX.moveTo(-260);
 stepperX.runToPosition();
   stepperX.moveTo(-250);
 stepperX.runToPosition();
  stepperX.moveTo(-260);
 stepperX.runToPosition();
   stepperX.moveTo(-250);
 stepperX.runToPosition();
  stepperX.moveTo(-260);
 stepperX.runToPosition();
   stepperX.moveTo(-250);
 stepperX.runToPosition();
  stepperX.moveTo(-260);
 stepperX.runToPosition();
   stepperX.moveTo(-250);
 stepperX.runToPosition();
  stepperX.moveTo(-260);
 stepperX.runToPosition();
   stepperX.moveTo(-250);
 stepperX.runToPosition();
  stepperX.moveTo(-260);
 stepperX.runToPosition();
   stepperX.moveTo(-250);
 stepperX.runToPosition();
  stepperX.moveTo(-260);
 stepperX.runToPosition();
   stepperX.moveTo(-250);
 stepperX.runToPosition();
  stepperX.moveTo(-260);
 stepperX.runToPosition();
   stepperX.moveTo(-250);
 stepperX.runToPosition();
  stepperX.moveTo(-260);
 stepperX.runToPosition();
   stepperX.moveTo(-250);
 stepperX.runToPosition();
  stepperX.moveTo(-260);
 stepperX.runToPosition();
   stepperX.moveTo(-250);
 stepperX.runToPosition();
  stepperX.moveTo(-260);
 stepperX.runToPosition();
   stepperX.moveTo(-250);
 stepperX.runToPosition();
  stepperX.moveTo(-260);
 stepperX.runToPosition();
   stepperX.moveTo(-250);
 stepperX.runToPosition();
  stepperX.moveTo(-260);
 stepperX.runToPosition();
   stepperX.moveTo(-250);
 stepperX.runToPosition();
  stepperX.moveTo(-260);
 stepperX.runToPosition();
   stepperX.moveTo(-250);
 stepperX.runToPosition();
  stepperX.moveTo(-260);
 stepperX.runToPosition();
   stepperX.moveTo(-250);
 stepperX.runToPosition();
  stepperX.moveTo(-260);
 stepperX.runToPosition();
   stepperX.moveTo(-250);
 stepperX.runToPosition();
  stepperX.moveTo(-260);
 stepperX.runToPosition();
   stepperX.moveTo(-250);
 stepperX.runToPosition();
  stepperX.moveTo(-260);
 stepperX.runToPosition();
   stepperX.moveTo(-250);
 stepperX.runToPosition();
  stepperX.moveTo(-260);
 stepperX.runToPosition();
   stepperX.moveTo(-250);
 stepperX.runToPosition();
  stepperX.moveTo(-260);
 stepperX.runToPosition();
   stepperX.moveTo(-250);
 stepperX.runToPosition();
  stepperX.moveTo(-260);
 stepperX.runToPosition();
   stepperX.moveTo(-250);
 stepperX.runToPosition();
  stepperX.moveTo(-260);
 stepperX.runToPosition();
   stepperX.moveTo(-250);
 stepperX.runToPosition();
  stepperX.moveTo(-260);
 stepperX.runToPosition();
 delay(5000);
  stepperX.moveTo(-250);
 stepperX.runToPosition();
  stepperX.moveTo(-260);
 stepperX.runToPosition();
  stepperX.moveTo(-250);
 stepperX.runToPosition();
  stepperX.moveTo(-260);
 stepperX.runToPosition();
  stepperX.moveTo(-250);
 stepperX.runToPosition();
  stepperX.moveTo(-260);
 stepperX.runToPosition();
  stepperX.moveTo(-250);
 stepperX.runToPosition();
  stepperX.moveTo(-260);
 stepperX.runToPosition();
  stepperX.moveTo(-250);
 stepperX.runToPosition();
  stepperX.moveTo(-260);
 stepperX.runToPosition();
  stepperX.moveTo(-250);
 stepperX.runToPosition();
  stepperX.moveTo(-260);
 stepperX.runToPosition();
  stepperX.moveTo(-250);
 stepperX.runToPosition();
  stepperX.moveTo(-260);
 stepperX.runToPosition();
  stepperX.moveTo(-250);
 stepperX.runToPosition();
  stepperX.moveTo(-260);
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

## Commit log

2025-03-14 RFID and Relays And Led scripts
2025-03-18 Led script
2025-03-19 use 9 volt power plug
2025-03-21 Create Homing Script
2025-03-21 Update Homing Script
2025-03-21 homing test script
2025-03-24 limit switch tester script
2025-03-31 updated relay script
2025-04-03 homing script updated
2025-04-09 worked on x-axis homing
2025-05-22 led tester
2025-05-24 model files upload
    [1.ipt, 10.ipt, 100.ipt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]
2025-05-24 more .stl
    [Mixer_1.stl, Motor_shaft_1.stl, NewTop v2.stl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]
2025-05-24 BOM Update
2025-06-03 parts list
    [Parts List.xlsx]
